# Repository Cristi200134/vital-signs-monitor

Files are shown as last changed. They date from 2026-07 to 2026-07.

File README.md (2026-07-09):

# VitalMonitor

Portable four-parameter vital-signs monitor (ECG, SpO2, temperature, respiration), built from scratch on an ESP32 for a biomedical engineering bachelor's at UMFST "G.E. Palade" Targu Mures. It reproduces the core functions of a clinical patient monitor using accessible parts. Working proof of concept, not a certified medical device.







## Highlights

- Four vital signs on one platform: heart rate from the ECG, SpO2, temperature, and respiration derived from the pulse signal.
- QRS detection validated on the MIT-BIH Arrhythmia Database (ANSI/AAMI EC57): F1 98.9%.
- Full engineering pack: schematic, costed bill of materials, 3D-printed enclosure, thesis.
- 3rd place at the Marisiensis International Medical Congress (UMFST, 2026).

## What it does

- ECG with heartbeat detection, SpO2 and temperature, plus a respiratory rate derived from the optical pulse signal.
- Local OLED display and a real-time web interface over the device's own WiFi access point.
- Three-level alarms with LED and buzzer, plus session logging to a microSD card with a real-time clock.

## Hardware

- ESP32 (dual core, FreeRTOS).
- ECG: AD8232 instrumentation amplifier and an external 16-bit ADC (ADS1115, 250 SPS), with a Butterworth filter cascade (high-pass 0.5 Hz, low-pass 40 Hz, notch 50 Hz, about 66 dB rejection at 50 Hz).
- SpO2 and respiration: MAX30102 optical sensor (ratio-of-ratios; respiration from the infrared DC modulation).
- Temperature: DS18B20. Clock: DS3231. Display: 128x64 OLED. Storage: microSD.
- Power: 1800 mAh LiPo, boost to 5 V, separate AMS1117 3.3 V rail for the analog section.
- Enclosure: plywood body with 3D-printed PLA panels (drawings in `hardware/`).

## Firmware

- C++/Arduino on FreeRTOS, eight tasks pinned across both cores by clinical priority, two mutexes (data and I2C), I2C at 400 kHz.
- ADS1115 runs in continuous mode so a 250 SPS ECG stream does not block the shared I2C bus.
- QRS detection: a simplified Pan-Tompkins (5-point derivative, squaring, 148 ms moving-window integration, adaptive SPKI/NPKI threshold, 200 ms refractory, averaging over 16 RR intervals).

## Validation

Heartbeat detection (simplified Pan-Tompkins) was tested on the MIT-BIH database, about 70,000 annotated beats over 30 records, with a 150 ms matching tolerance, following ANSI/AAMI EC57.

| Metric | Value | Method |
|---|---|---|
| Sensitivity (Se) | 98.66% | MIT-BIH, 30 records, ~70,000 beats |
| Positive predictivity (+P) | 99.11% | same |
| F1 score | 98.9% | same |
| ECG filter | SNR > 60 dB, stable (poles inside the unit circle) | simulation |

## Known limitations 

- The false-alarm rate is above the target I set for it.
- Latency, CPU load and battery life are budget estimates, not bench measurements.
- It is a research prototype, not a certified medical device.

## Repository structure

- `firmware/` ESP32 source (config, sensors, FreeRTOS tasks, web server).
- `hardware/` schematic (PDF), bill of materials, enclosure files (STL).
- `validation/` MATLAB scripts and the MIT-BIH validation.
- `docs/` thesis extract, device photos, validation captures.

## Tech

ESP32, FreeRTOS, C++, AD8232, ADS1115, MAX30102, DS18B20, MATLAB, PlatformIO.

## Author

Cristi Dica, biomedical engineer, Targu Mures. 

## License

MIT. See `LICENSE`.

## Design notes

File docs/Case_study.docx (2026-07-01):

Technical Case Study

VitalMonitor: a portable four-parameter vital signs monitor on the ESP32 platform

Dimension | Detail
Domain | biomedical engineering, embedded systems, biomedical signal processing
Platform | ESP32-WROOM-32 (dual core), C++/Arduino, FreeRTOS, PlatformIO
Parameters | ECG with heart rate, SpO2, temperature (measured directly); respiration (derived from the PPG signal)
Scope covered | hardware architecture, firmware, web application, CAD enclosure, numerical validation
Headline result | QRS detection on MIT-BIH: Se 98.67% / +P 99.11% / F1 98.89%
Cost | under 607 RON in components, below one tenth of a commercial multiparameter monitor
Battery life | about 7.6 h in active mode (1800 mAh LiPo, roughly 236 mA draw)

# 1. Context and problem

Patient deterioration is almost always preceded by changes in vital signs, which is why continuous monitoring is part of clinical practice and of standardized scores such as NEWS2. The barrier is not what we measure but access: classic multiparameter monitoring relies on expensive, bulky equipment tied to the ward. Outside the hospital, in home care or in resource-limited settings, it is missing.

The design question was whether the four common vital signs can be integrated on a single portable platform, an order of magnitude cheaper than a commercial monitor, without sacrificing the reliability of the part that matters most clinically, the correct detection of heartbeats.

# 2. Objectives and requirements

Functional requirements were fixed before implementation, each with a measurable criterion. The table summarizes the final state against the objectives.

Code | Requirement | Criterion | Status
F1 | ECG acquisition and analysis | QRS detection validated on clinical data | met (MIT-BIH)
F2 | SpO2 estimation | formula vs reference, Bland-Altman analysis | partial (subject validation pending)
F3 | heart rate | derived from ECG, averaged over 16 RR intervals | met
F4 | temperature | dedicated digital sensor | met
F5 | respiration | derived from signal, no extra sensor | met (on test signal)
F6 | real-time display | latency under 500 ms | met (estimated budget)
N1 | low cost | fraction of a commercial monitor | met (under 607 RON)

# 3. System architecture

The system is organized into six functional zones: analog acquisition, digital sensors, processing, power, display and communication. Coordination is handled by a dual-core ESP32, chosen over an Arduino Uno board for its compute headroom, built-in WiFi, and the ability to separate real-time acquisition from display and communication.

Three sensor chains produce four vital values. The ECG chain yields heart rate through QRS detection. The optical sensor yields oxygen saturation and, from the same signal, respiratory rate. The digital sensor yields temperature. Heart rate is therefore derived from the ECG, not from the optical sensor, and respiration is derived from the modulation of the pulse signal.

# 4. Engineering decisions and trade-offs

## 4.1. ECG chain and 16-bit conversion

The ECG signal is on the order of millivolts and easily corrupted, so it is captured by the AD8232 instrumentation amplifier (fixed gain of 100 V/V, common-mode rejection typically 86 dB up to 60 Hz, Driven Right Leg loop). Conversion does not use the ESP32 internal converter, which is too noisy and only 12-bit, but an external 16-bit ADS1115 on the ±6.144 V range. One quantization step is LSB = 6.144 / 32768 = 187.5 µV, that is about 1.875 µV referred to the electrodes after the gain of 100, fine enough for the QRS complex. The sampling rate is 250 SPS, above twice the 40 Hz useful band, the choice being driven by the accuracy of locating the R peak.

## 4.2. Continuous mode on the ADS1115

A subtle but important decision was running the converter in continuous mode rather than one-shot. In one-shot, each conversion at 250 SPS blocked the I2C bus for about 4 ms, starving the optical sensor, the clock and the display, which share that bus. In continuous mode the firmware reads the result register in about 0.5 ms, leaving the bus free for the rest of the interval. This was a system integration problem, not an algorithmic one, and it shows how much access scheduling on a shared resource matters.

## 4.3. QRS detection, a simplified Pan-Tompkins

Beat detection reproduces the core of the Pan-Tompkins algorithm: a five-point derivative, squaring, integration over a 37-sample moving window (148 ms at 250 SPS), and an adaptive threshold with two exponential estimates, one for the signal (SPKI) and one for noise (NPKI), with T = NPKI + 0.25 · (SPKI - NPKI). A 200 ms refractory period and averaging over 16 RR intervals stabilize the rate. It is a simplified variant, without searchback and without dual thresholds, a trade-off justified by real-time execution on a microcontroller.

## 4.4. SpO2 and respiration from the same optical signal

Saturation uses the ratio-of-ratios method, R = (AC_red/DC_red) / (AC_infrared/DC_infrared), mapped through the empirical curve SpO2 = -45.06·R^2 + 30.35·R + 94.85 from the sensor application note. From the DC component of the infrared signal, modulated by breathing through cardio-respiratory coupling, the firmware extracts respiratory rate with a band-pass filter formed from the difference of two exponential moving averages (band roughly 0.016 to 0.8 Hz) and zero-crossing detection. A single optical sensor thus covers two parameters, with no extra hardware.

## 4.5. Concurrency across two cores

The firmware runs on FreeRTOS with eight tasks explicitly pinned across the two cores. On the acquisition core, ECG has the highest priority, followed by the optical sensor, alarms, temperature, display and buttons; the other core runs the WebSocket server and SD logging. Two mutexes, one on the shared data structure and one on the I2C bus, prevent collisions. The separation guarantees that the deterministic 4 ms acquisition is never delayed by display or communication.

## 4.6. Power with dual regulation

Power starts from an 1800 mAh LiPo battery, with dedicated charging and a master switch. A boost converter produces a 5 V rail, from which an AMS1117 linear regulator derives a 3.3 V supply used only by the analog section, separate from the digital supply of the ESP32. The dual regulation keeps noisy consumers away from the sensitive measurement chain. Battery voltage is tracked through a resistive divider on the converter second channel.

# 5. Technical challenges solved

### The offset transient that dropped sensitivity to 49%

On the first run of detection on MIT-BIH, sensitivity was only 49%. The cause was not the algorithm but the data: the raw signal has a large DC component which, passed through the high-pass filter, produced a large startup transient. The adaptive threshold, computed exactly on that beginning, was inflated and missed most beats. The fix was to remove the signal mean and to skip the first second when initializing the threshold. Sensitivity rose to 98.67%. The lesson, statable directly to the committee: a correct algorithm can appear to fail because of a data preparation issue.

### Filter chain stability

The filter cascade was confirmed stable by the pole positions of each biquad section, all inside the unit circle. The frequency response shows 3 dB attenuation at the 0.5 and 40 Hz cutoffs and about 66 dB at 50 Hz, enough to suppress mains interference. After filtering, the signal-to-noise ratio exceeds the 60 dB threshold considered necessary for a reliable clinical reading.

# 6. Validation and results

Validation was designed component by component, with the established metric for each. The important distinction, which a committee values, is between what was validated on real clinical data and what was estimated or simulated.

Component | Method and result | Type
QRS detection | MIT-BIH, 30 records, about 70,000 beats, 150 ms tolerance, AAMI EC57 protocol: Se 98.67%, +P 99.11%, F1 98.89% | real clinical data
ECG filter | poles inside the unit circle (stable), 3 dB at 0.5 and 40 Hz, about 66 dB at 50 Hz, SNR above 60 dB | simulation
SpO2 | error under 2% vs the reference table for R below 0.70; Bland-Altman analysis | deterministic + simulated
Display latency | budget under 500 ms (IEC 60601-2-27 reference) | estimate
CPU load | under 80% per core | estimate
Battery life | about 7.6 h in active mode | calculation from currents

Validation honesty: the Bland-Altman analysis for SpO2 used simulated pairs, not measurements on subjects with a reference co-oximeter. The principle is correct, but clinical validation of saturation remains future work. QRS detection, by contrast, was validated on real clinical data, which makes it the strongest part of the project.

# 7. Acknowledged limitations

- blood pressure is not measured; the system covers four of the five common parameters.
- SpO2 validation is on simulated pairs, not on subjects; empirical calibration of the R curve requires controlled desaturation studies.
- latency, CPU load, battery life and SNR are budgets and simulations from specifications, not bench measurements.
- QRS detection was validated as a MATLAB reimplementation with the same coefficients and thresholds as the firmware, not as the compiled binary running on the chip.
- there is no full-system functional validation on a human subject over time yet.
- it is a research prototype, not a certified device.

# 8. Standards considered

The design respected the spirit of the relevant standards framework, as an exercise in rigor: IEC 60601-1 and 60601-1-8 for safety and alarms, IEC 62304 for the software life cycle, ISO 14971 for risk management and ISO 80601-2-61 for pulse oximetry, in the context of the European Medical Device Regulation. The system was not submitted for certification, and this is stated explicitly.

# 9. Impact and what the project demonstrates

The project demonstrates the vertical integration of a complete medical device by a single person: from the sensitive analog chain and the real-time firmware, through the validated processing algorithms, to the web application, the CAD enclosure and the validation protocol. The value lies not in a new algorithm but in coherently bringing the four parameters together on a low-cost platform and validating the critical part on real clinical data, at a cost an order of magnitude below a commercial monitor.

# 10. Lessons and next steps

- integrating a shared resource (the I2C bus) can be more limiting than the algorithm itself; access scheduling matters.
- data preparation (offset, transients) can mask a correct algorithm; diagnosis separates the two.
- validation honesty, a clear separation between real data and estimates, is worth more than a polished number.
- next steps: validate SpO2 on subjects against a reference, bench-measure latency and battery life, run the detector on the actual binary, and a full integrated functional pilot.

# 11. Technology stack

Layer | Components
Hardware | ESP32-WROOM-32, AD8232, ADS1115 (16-bit), MAX30102, DS18B20, DS3231, 128x64 OLED, SD card, TP4056, MT3608, AMS1117, 1800 mAh LiPo
Firmware | C++/Arduino, FreeRTOS (8 tasks, 2 cores), PlatformIO, two mutexes, I2C at 400 kHz
Algorithms | simplified Pan-Tompkins, ratio-of-ratios, RIIV respiration, Butterworth biquad filters (HP/LP/notch)
Web | SoftAP, ESPAsyncWebServer, WebSocket, LittleFS, HTML/JS monitoring and history pages
Validation | MATLAB (14 scripts), MIT-BIH database via PhysioNet, numerical checks
Mechanics | CAD in Fusion 360, plywood body, 3D-printed PLA panels, aluminum profiles

# Selected references

[1] Pan J, Tompkins WJ. A real-time QRS detection algorithm. IEEE Trans Biomed Eng. 1985.

[2] Moody GB, Mark RG. The impact of the MIT-BIH Arrhythmia Database. IEEE EMB. 2001.

[3] Goldberger AL, et al. PhysioBank, PhysioToolkit, and PhysioNet. Circulation. 2000.

[4] AAMI. Testing and reporting performance of cardiac rhythm algorithms (EC57).

[5] Giavarina D. Understanding Bland-Altman analysis. Biochem Med. 2015.

[6] Charlton PH, et al. Breathing rate estimation from the ECG and PPG: a review. IEEE Rev Biomed Eng. 2018.

[7] Nitzan M, Romem A, Koppel R. Pulse oximetry: fundamentals and technology update. 2014.

[8] Analog Devices, AD8232 datasheet; Maxim, MAX30102 / AN6409; Espressif, ESP32-WROOM-32 datasheet.

Indicative case study, compiled from the code and data of the VitalMonitor project.

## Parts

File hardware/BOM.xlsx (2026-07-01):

VitalMonitor — Listă de materiale (BOM)
Prețuri în RON. Electronica: prețuri din lucrare (Anexa B). Carcasă: estimativ, de verificat.
Nr. | Categorie | Componentă | Cant. | Preț (RON)
1 | Electronică | Placă de dezvoltare ESP32-WROOM-32 (DevKit1) | 1 | 42.00
2 | Electronică | Modul senzor ECG AD8232 (kit cu electrozi și cabluri) | 1 | 39.25
3 | Electronică | Senzor pulsoximetru MAX30102 (puls și SpO2) | 1 | 26.99
4 | Electronică | Senzor de temperatură impermeabil DS18B20 (sondă) | 1 | 7.10
5 | Electronică | Modul ADC ADS1115 (16 biți, I2C) | 1 | 14.44
6 | Electronică | Modul RTC DS3231 cu baterie LIR2032 | 1 | 26.16
7 | Electronică | Afișaj OLED 0,96″ I2C, SSD1306, 128×64 px | 1 | 13.74
8 | Electronică | Acumulator LiPo 103450, 3,7 V, 1800 mAh | 1 | 83.99
9 | Electronică | Modul de încărcare TP4056 USB-C, cu protecție | 1 | 3.90
10 | Electronică | Modul de ridicare a tensiunii MT3608 (HW-626) | 1 | 6.66
11 | Electronică | Regulator de tensiune AMS1117, 3,3 V | 1 | 4.07
12 | Electronică | Modul cititor microSD (SPI) | 1 | 3.62
13 | Electronică | Card microSD 32 GB (din stoc propriu) | 1 | 0.00
14 | Electronică | Buton PBS-110 (start/stop monitorizare) | 1 | 1.26
15 | Electronică | Buton PBS-110 (mod overnight) | 1 | 2.06
16 | Electronică | Buton PBS-110 (marcare eveniment) | 1 | 2.06
17 | Electronică | Buton PBS-110 (silențiere alarmă) | 1 | 1.49
18 | Electronică | Buton capacitiv TTP223 (touch) | 2 | 5.00
19 | Electronică | Întrerupător On-Off (alimentare principală) | 1 | 4.11
20 | Electronică | LED RGB de 10 mm, catod comun | 3 | 5.52
21 | Electronică | Buzzer pasiv 5 V | 2 | 2.40
22 | Electronică | Modul buzzer activ (rezervă) | 1 | 3.00
23 | Electronică | Conector aviatic 3 pini ELS-CA3P (metalic) | 2 | 40.66
24 | Electronică | Conector aviatic 4 pini ELS-CA4P (metalic) | 1 | 25.41
25 | Electronică | Set cabluri 24 AWG, 15 cm, negru | 1 | 3.04
26 | Electronică | Set cabluri 24 AWG, 15 cm, roșu | 1 | 3.04
27 | Electronică | Rezistență 4,7 kΩ, film metalic (pull-up I2C / 1-Wire) | 4 | 16.72
28 | Electronică | Rezistență 100 kΩ, 1 W, film metalic (divizor baterie) | 3 | 24.42
29 | Electronică | Rezistență 100 kΩ, 0,25 W, carbon (filtru anti-aliasing) | 2 | 7.74
30 | Electronică | Rezistență 10 kΩ, 0,25 W, carbon | 10 | 39.20
31 | Electronică | Rezistență 1 kΩ, 0,25 W, carbon (limitare LED RGB) | 3 | 11.70
32 | Electronică | Rezistență 100 Ω, 0,5 W, carbon (limitare buzzer) | 2 | 8.96
33 | Electronică | Rezistență 68 Ω, 0,25 W, carbon | 2 | 7.60
34 | Electronică | Rezistență 4,7 Ω, 0,25 W, carbon | 3 | 11.58
35 | Electronică | Condensator ceramic 100 nF, 50 V (decuplare VCC) | 7 | 25.55
36 | Electronică | Condensator electrolitic 10 µF, 50 V (Nichicon) | 4 | 13.32
37 | Electronică | Condensator electrolitic 10 µF, 35 V (Samwha) | 1 | 4.26
38 | Electronică | Tranzistor NPN BC547 (TO-92, comandă buzzer) | 1 | 1.47
39 | Electronică | Placă PCB prototip, 100 × 150 mm | 2 | 19.36
40 | Electronică | Set distanțiere M3, 15 mm (alamă) | 1 | 7.26
41 | Electronică | Set piulițe M3, inox A2 | 1 | 8.01
42 | Electronică | Bandă de cupru adezivă, 20 mm (ecranare ECG / cușcă Faraday) | 1 | 29.05
43 | Carcasă | Placaj de mesteacăn (corp carcasă, tăiat laser) — aprox. | 1 | 25.00
44 | Carcasă | Filament PLA (~200 g, piese imprimate 3D) — aprox. | 1 | 20.00
45 | Carcasă | Profile / colțare de aluminiu (rigidizare) — aprox. | 1 | 30.00
46 | Carcasă | Șuruburi de lemn, adeziv și accesorii de montaj — aprox. | 1 | 20.00
47 | Carcasă | Tabletă (ecran principal, montată pe panou frontal) — de completat | 1 | 0.00
 |  | TOTAL (RON) |  | 702.17

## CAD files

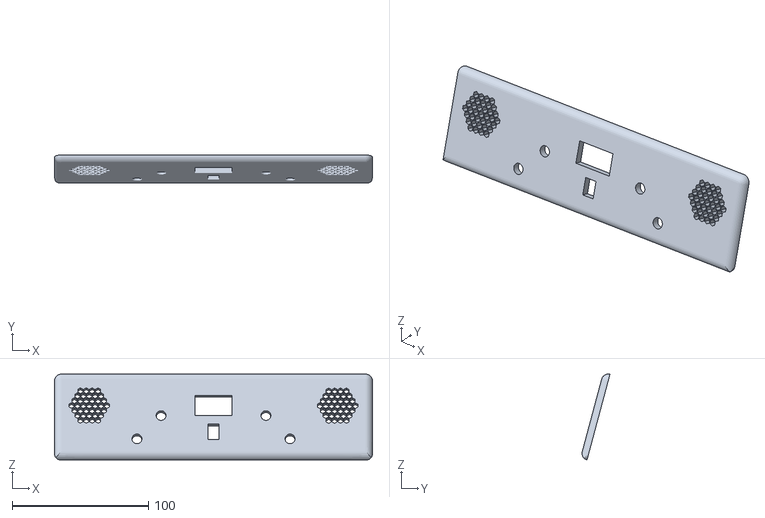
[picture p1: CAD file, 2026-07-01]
hardware/cad/zona oled+btn.stl
233.0 x 20.5 x 63.0

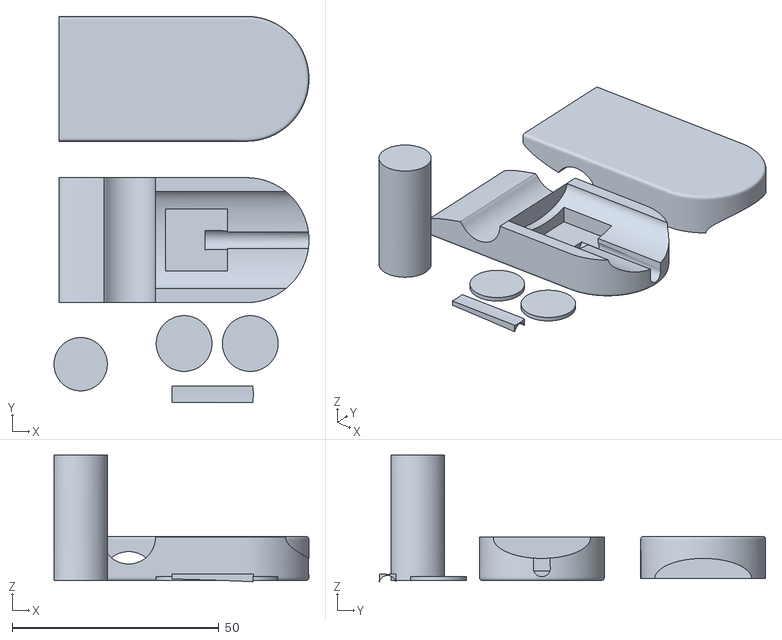
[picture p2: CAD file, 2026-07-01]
hardware/cad/pulsoximetru.stl
61.7 x 93.4 x 30.6

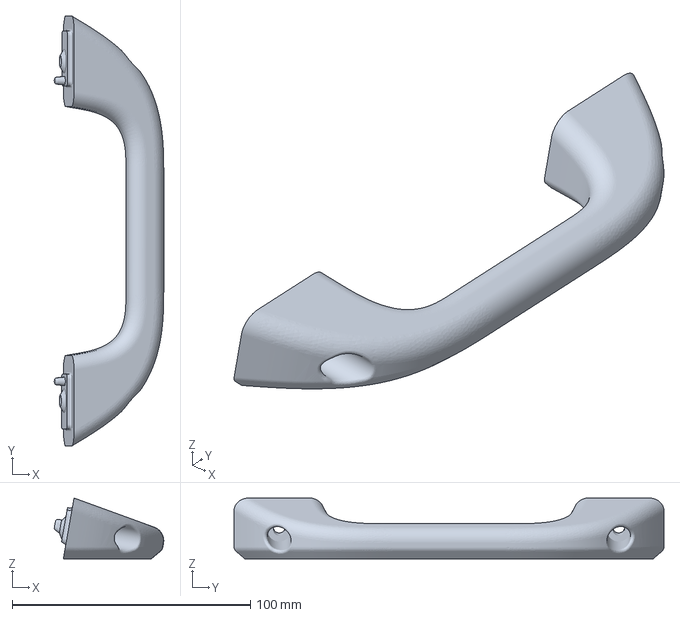
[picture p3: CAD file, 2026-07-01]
hardware/cad/maner.3mf
46.0 x 180.5 x 25.6 mm

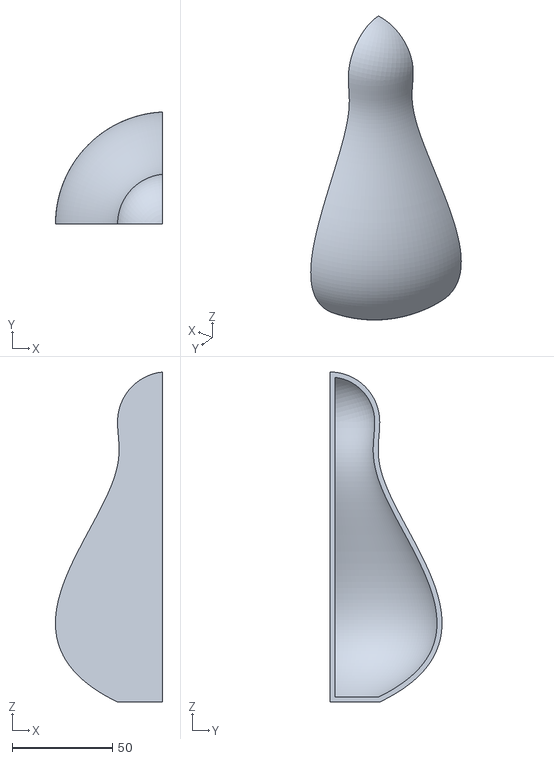
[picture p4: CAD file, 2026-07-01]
hardware/cad/zona led.stl
53.5 x 56.0 x 164.9

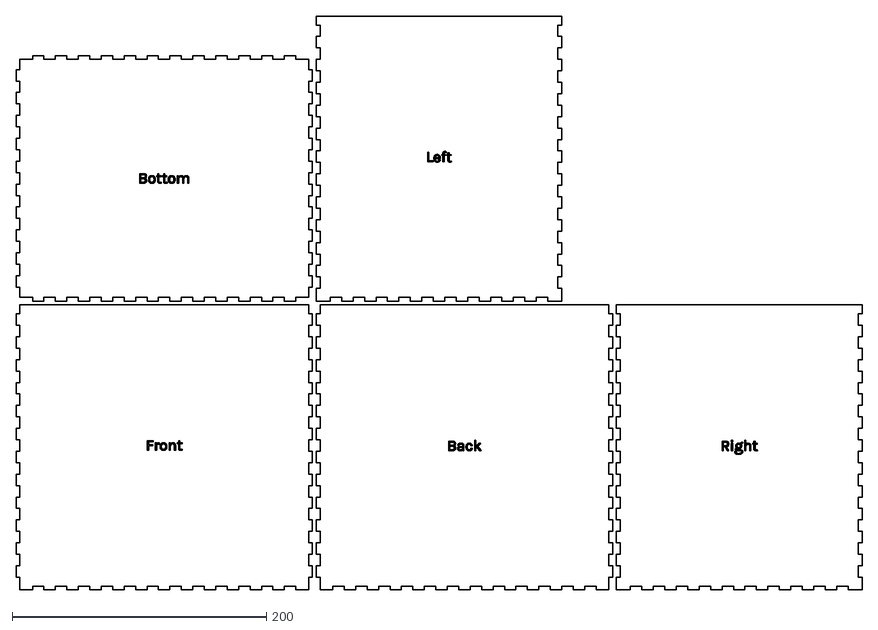
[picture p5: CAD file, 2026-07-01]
hardware/cad/box.dxf
665.0 x 451.0

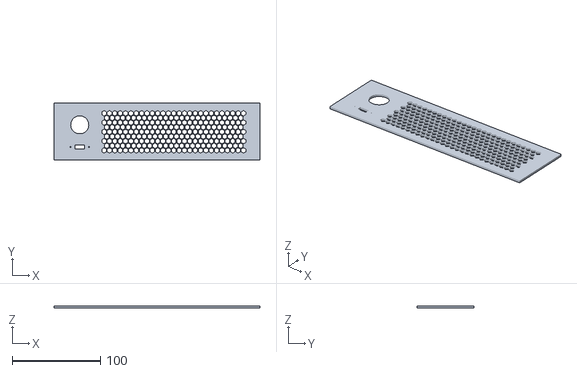
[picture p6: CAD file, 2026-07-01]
hardware/cad/panou spate.stl
233.0 x 65.0 x 2.50

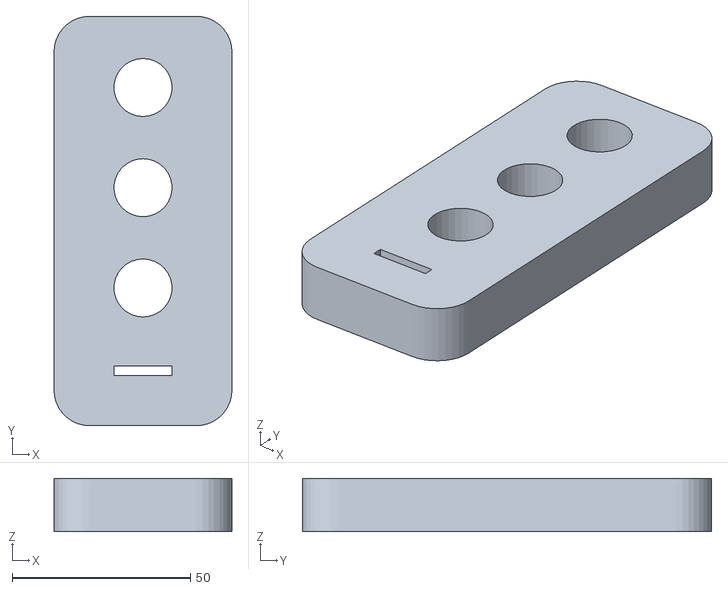
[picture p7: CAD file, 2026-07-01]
hardware/cad/zona conectori.stl
50.0 x 115.0 x 15.0

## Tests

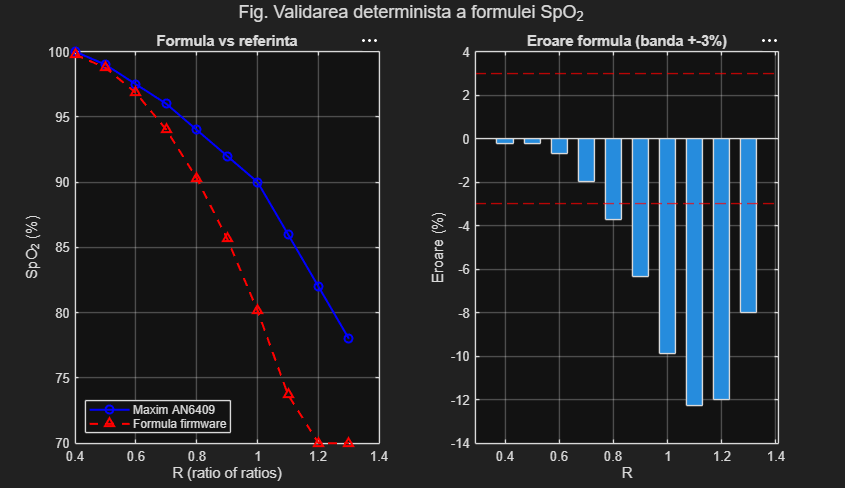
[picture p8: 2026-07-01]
docs/validation_photos/2spo2_bland1 (2).png

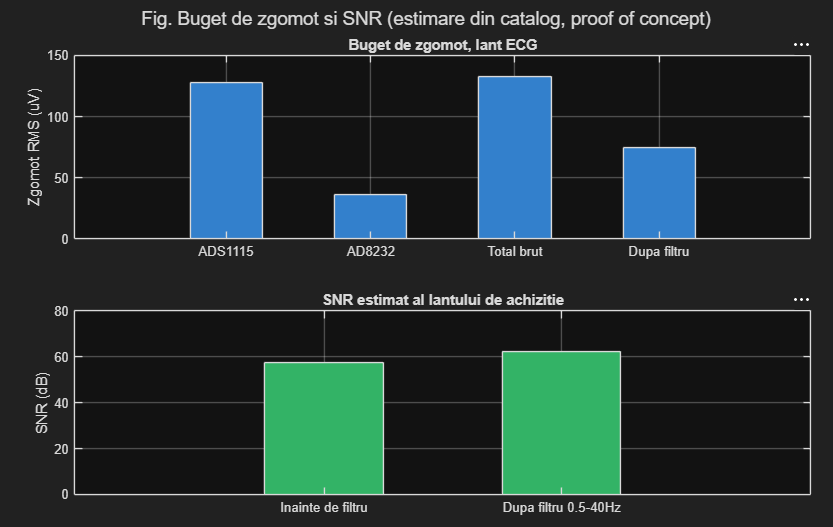
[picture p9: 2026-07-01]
docs/validation_photos/7zgomot_snr.png

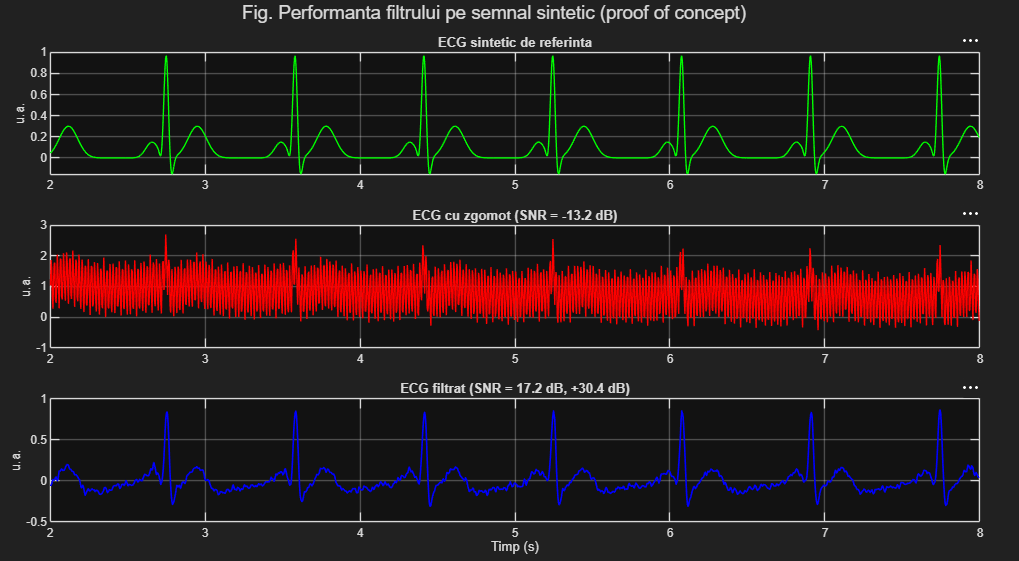
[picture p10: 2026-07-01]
docs/validation_photos/1filtru_ecg3 (2).png

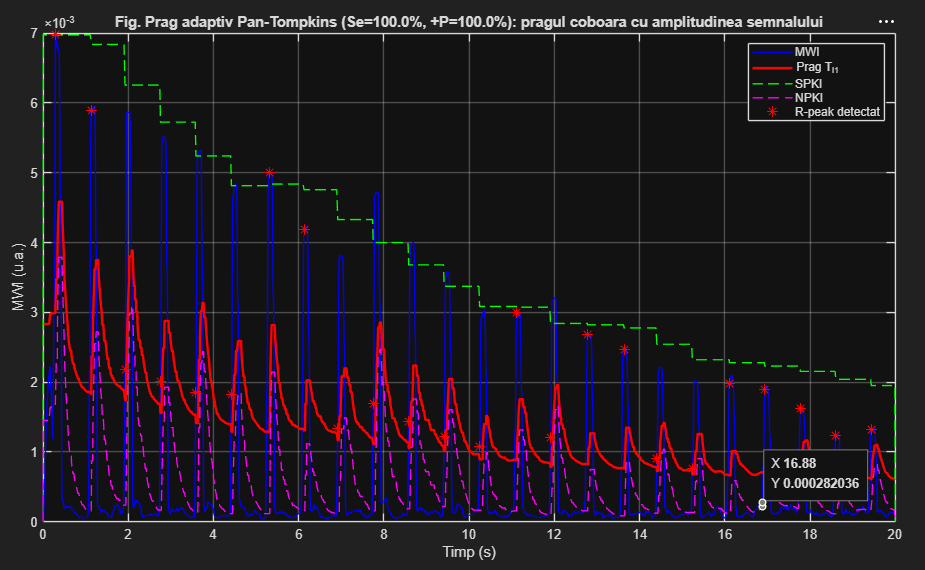
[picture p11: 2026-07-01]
docs/validation_photos/4prag_adaptiv.png

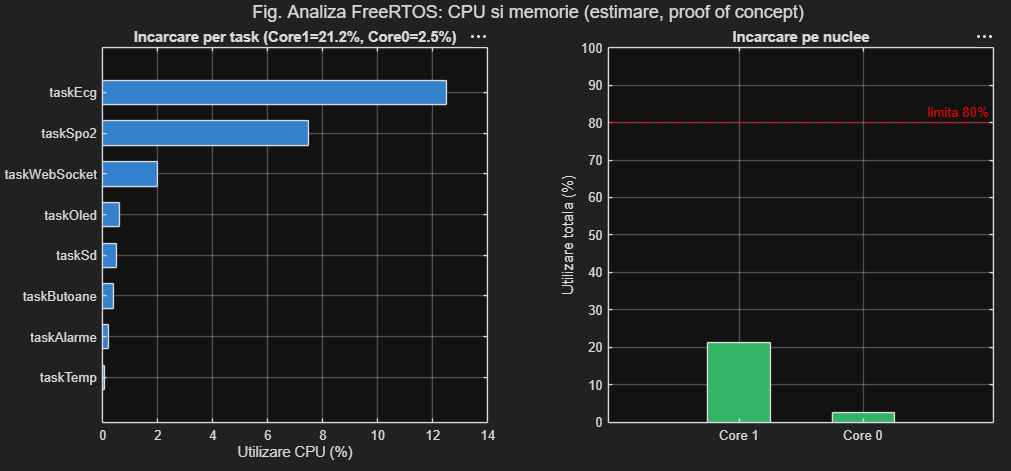
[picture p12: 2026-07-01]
docs/validation_photos/3cpu_freertos.png

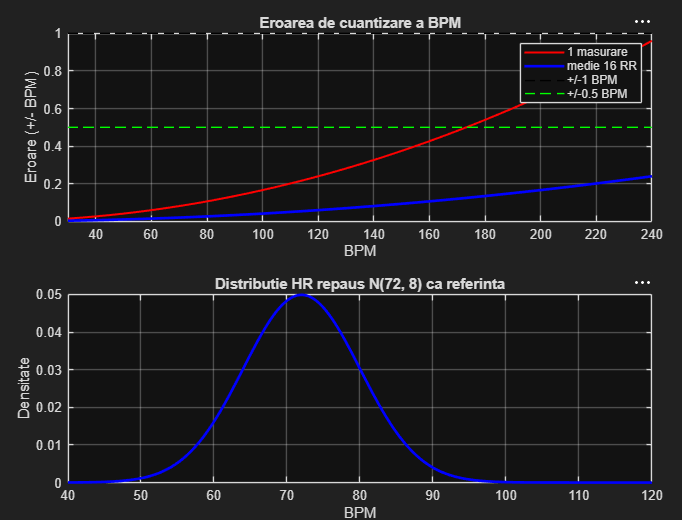
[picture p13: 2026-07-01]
docs/validation_photos/8precizie_bpm.png

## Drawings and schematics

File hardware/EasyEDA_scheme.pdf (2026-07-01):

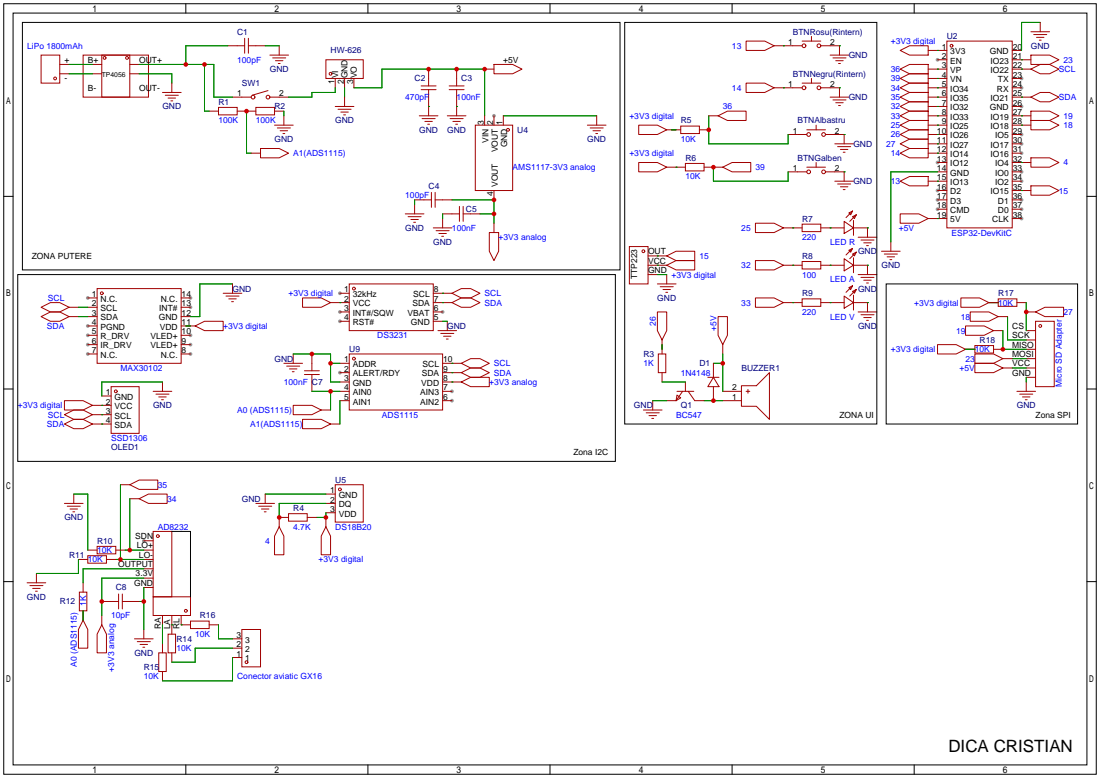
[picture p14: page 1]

HW-626 VI GND VO

VLED+ 10 VDD 11 GND 12 INT# 13 N.C. 14

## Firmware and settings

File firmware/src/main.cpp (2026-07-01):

//main.cpp — vitalmonitor (orchestrator freertos)
//workflow 
//  standby - [btn_rec sau "sesiune_noua" prin ws] - monitoring - [stop]
//arhitectura dual-core:
//  core 1: ecg(5) > spo2(4) > alarme(3) > temp(2) > oled(2) > btn(1)
//  core 0: websocket(3) > sd(2)
//mutex-uri:
//  g_mutex— acces campuri vitaldata (max 10ms wait)
//  g_i2c_mutex— serializeaza bus-ul i2c intre ads1115, max30102, rtc, oled

#define VITAL_DATA_IMPL
#include "vital_data.h"
#include "config.h"

#include <Arduino.h>
#include <Wire.h>
#include <WiFi.h>
#include <LittleFS.h>
#include <ESPAsyncWebServer.h>
#include <AsyncTCP.h>
#include <ArduinoJson.h>
#include <SD.h>
#include "esp_wifi.h"

#include "ecg_filter.h"
#include "ecg_sensor.h"
#include "spo2_sensor.h"
#include "temp_sensor.h"
#include "rtc_sensor.h"
#include "sd_logger.h"
#include "oled_display.h"
#include "ws_server.h"
#include "led_control.h"
#include "alarm_manager.h"

//obiecte globale
AsyncWebServer  g_server(WEB_PORT);
AsyncWebSocket  g_ws(WS_PATH);

EcgSensor    g_ecg;
Spo2Sensor   g_spo2;
TempSensor   g_temp;
RtcSensor    g_rtc;
SdLogger     g_sd;
OledDisplay  g_oled;
WsServer     g_wsrv;
LedControl   g_led;
AlarmManager g_alarm;

//task ecg — core 1, prioritate 5, 250 sps
//vtaskdelayuntil - 4ms intre esantioane
//i2c-ul protejat de g_i2c_mutex in ecgsensor::citestesi()
void taskEcg(void* pv) {
    g_ecg.init();
    TickType_t tWake = xTaskGetTickCount();

    while (true) {
        bool activ = false;
        if (LOCK_VITALS()) { activ = g_vitals.monitoring_active; UNLOCK_VITALS(); }
        g_ecg.citesteSi(&g_vitals, g_mutex, activ);
        vTaskDelayUntil(&tWake, pdMS_TO_TICKS(4));
    }
}

//task spo2 — core 1, prioritate 4, 50 sps
// g_i2c_mutex in spo2sensor::citestesi()
//cu mutex, spo2 asteapta pana ecg elibereaza bus-ul (4ms max)
void taskSpo2(void* pv) {
    g_spo2.init();
    TickType_t tWake = xTaskGetTickCount();

    while (true) {
        bool activ = false;
        if (LOCK_VITALS()) { activ = g_vitals.monitoring_active; UNLOCK_VITALS(); }
        if (activ) g_spo2.citesteSi(&g_vitals, g_mutex);
        vTaskDelayUntil(&tWake, pdMS_TO_TICKS(20));
    }
}

//task temperatura + rtc — core 1, prioritate 2, la 2s
//ds18b20 - onewire, fara i2c, fara mutex
//rtc - i2c, protejat in rtcsensor::actualizeazaora()
void taskTemp(void* pv) {
    g_temp.init();

    while (true) {
        //rtc-ul ruleaza mereu (avem nevoie pentru ceas si timestamp csv)
        g_rtc.actualizeazaOra(&g_vitals, g_mutex);

        bool activ = false;
        if (LOCK_VITALS()) { activ = g_vitals.monitoring_active; UNLOCK_VITALS(); }
        if (activ) g_temp.citesteSi(&g_vitals, g_mutex);

        vTaskDelay(pdMS_TO_TICKS(TEMP_INTERVAL_MS));
    }
}

//task oled — core 1, prioritate 2, refresh la 500ms
//disp.display() (i2c) e protejat in oleddisplay::afiseaza()
//in overnight: ecran afiseaza  "overnight" + ora curenta
void taskOled(void* pv) {
    g_oled.init();

    while (true) {
        VitalData snap = snapVitals();

        if (snap.overnight_active) g_oled.afiseazaOvernight(snap);
        else                       g_oled.afiseaza(snap);

        vTaskDelay(pdMS_TO_TICKS(500));
    }
}

//task websocket — core 0, prioritate 3
//"wave" la 100ms — batch ecg + spo2
//"num"  la 2s    — date numerice complete

void taskWebSocket(void* pv) {
    vTaskDelay(pdMS_TO_TICKS(2000));    //asteptam initializarea wifi

    TickType_t tWave    = xTaskGetTickCount();
    TickType_t tNumeric = xTaskGetTickCount();
    TickType_t tCleanup = xTaskGetTickCount();

    while (true) {
        TickType_t tNow = xTaskGetTickCount();

        if ((tNow - tWave) >= pdMS_TO_TICKS(WAVE_TX_MS)) {
            tWave = tNow;
            g_wsrv.trimiteBatch(&g_vitals, g_mutex, &g_ws);
        }

        if ((tNow - tNumeric) >= pdMS_TO_TICKS(NUMERIC_TX_MS)) {
            tNumeric = tNow;
            if (LOCK_VITALS()) {
                g_vitals.ws_clients = (uint8_t)g_ws.count();
                UNLOCK_VITALS();
            }
            g_wsrv.trimiteNumeric(&g_vitals, g_mutex, &g_ws);
        }

        //cleanup la 5s pe core 0 (acelasi cu ws-ul) — evita race condition
        if ((tNow - tCleanup) >= pdMS_TO_TICKS(5000)) {
            tCleanup = tNow;
            g_ws.cleanupClients();
        }

        vTaskDelay(pdMS_TO_TICKS(10));
    }
}

//task sd logger — core 0, prioritate 2, la 1s
//tranzitie monitoring false->true: deschide fisier nou
//tranzitie monitoring true->false: inchide fisierul
//incrementeaza probe_count si uptime_s la fiecare rand scris
void taskSd(void* pv) {
    bool sdOk = g_sd.init();
    if (LOCK_VITALS()) {
        g_vitals.sd_ok      = sdOk;
        g_vitals.sd_free_gb = sdOk ? g_sd.spatioLiber() : 0.0f;
        UNLOCK_VITALS();
    }

    bool wasActiv = false;

    while (true) {
        VitalData snap = snapVitals();
        bool activ = snap.monitoring_active;

        if (activ && !wasActiv)   g_sd.deschideSesiune(snap);
        else if (!activ && wasActiv) g_sd.inchide();

        if (activ) {
            g_sd.scrieRand(snap);
            if (LOCK_VITALS()) {
                g_vitals.probe_count++;
                g_vitals.uptime_s++;
                g_vitals.sd_free_gb    = g_sd.spatioLiber();
                g_vitals.sd_almost_full = g_sd.aproapePlin();
                UNLOCK_VITALS();
            }
        }

        wasActiv = activ;
        vTaskDelay(pdMS_TO_TICKS(SD_LOG_INTERVAL_MS));
    }
}

//task alarme + led + buzzer — core 1, prioritate 3, la 500ms
//in standby: led albastru clipeste lent, buzzer-ul oprit
//in monitoring: led-ul si buzzer-ul urmaresc nivelul de alarma
void taskAlarme(void* pv) {
    g_alarm.init();
    g_led.init();

    while (true) {
        VitalData snap = snapVitals();

        if (snap.monitoring_active) {
            AlarmResult res = g_alarm.evalueaza(snap);

            //auto-exit din overnight, doar pentru alarmele physio (nu lead-off/baterie)
            if (snap.overnight_active && res.isPhysio && res.level >= 2) {
                if (LOCK_VITALS()) { g_vitals.overnight_active = false; UNLOCK_VITALS(); }
                snap.overnight_active = false;
                Serial.printf("[overnight] auto-exit: %s (nivel %d)\n", res.msg, res.level);
            }

            //auto-mark csv: pe tranzitia la nivel 3 (critic), marcheaza evenimentul
            //asa coloana "ev" din csv arata "DA" la momentul aparitiei alarmei critice
            static uint8_t prevAlarmLevel = 0;
            if (res.level >= 3 && prevAlarmLevel < 3) {
                g_sd.marcheazaEveniment();
                Serial.printf("[alarm-ev] critic auto-marcat in csv: %s\n", res.msg);
            }
            prevAlarmLevel = res.level;

            if (LOCK_VITALS()) {
                g_vitals.alarm_level = res.level;
                strncpy(g_vitals.alarm_msg, res.msg, sizeof(g_vitals.alarm_msg) - 1);
                UNLOCK_VITALS();
            }

            if (snap.overnight_active) {
                //in overnight: led galben fulger scurt la 10s, buzzer mut
                bool on = (millis() % 10000) < 200;
                digitalWrite(PIN_LED_R, on ? HIGH : LOW);
                digitalWrite(PIN_LED_G, on ? HIGH : LOW);
                digitalWrite(PIN_LED_B, LOW);
                noTone(PIN_BUZZER);
            } else {
                g_led.aplicaAlarma(res.level, snap.bat_pct);
                g_alarm.sunaBuzzer(res.level);
            }
        } else {
            //standby (eventual + overnight): albastru clipeste / overnight = stins
            if (snap.overnight_active) {
                digitalWrite(PIN_LED_R, LOW);
                digitalWrite(PIN_LED_G, LOW);
                digitalWrite(PIN_LED_B, LOW);
            } else {
                bool on = (millis() / 1000) % 2;
                digitalWrite(PIN_LED_R, LOW);
                digitalWrite(PIN_LED_G, LOW);
                digitalWrite(PIN_LED_B, on ? HIGH : LOW);
            }
            noTone(PIN_BUZZER);
        }

        vTaskDelay(pdMS_TO_TICKS(500));
    }
}

//task butoane — core 1, prioritate 1, polling la 50ms
//btn_men (gpio36 albastru — paginile oled
//btn_sil (gpio39 galben)  — silentiere buzzer 1 minut
//btn_sel (gpio14 negru)   — toggle overnight (single press)
//btn_rec (gpio13 rosu)   — start / stop monitorizare
//btn_ev  (gpio15 ttp223)  — marcheaza eveniment in csv
void taskButoane(void* pv) {
    bool prevMen = HIGH, prevSil = HIGH, prevSel = HIGH, prevRec = HIGH, prevEv = LOW;

    while (true) {
        bool curMen = digitalRead(PIN_BTN_MEN);
        bool curSil = digitalRead(PIN_BTN_SIL);
        bool curSel = digitalRead(PIN_BTN_SEL);
        bool curRec = digitalRead(PIN_BTN_REC);
        bool curEv  = digitalRead(PIN_BTN_EV);

        //btn_men — pagina urmatoare oled
        if (prevMen == HIGH && curMen == LOW) {
            g_oled.nextPagina();
        }

        //btn_sil — silentiere buzzer 1 minut 
        if (prevSil == HIGH && curSil == LOW) {
            g_alarm.mutePentru(BTN_SIL_MS);
            g_wsrv.trimiteCmdButon(&g_ws, "btn_sil");
            Serial.println("[btn_sil] buzzer silentiat 1 minut");
        }

        //btn_sel — toggle overnight 
        if (prevSel == HIGH && curSel == LOW) {
            bool nou = false;
            if (LOCK_VITALS()) {
                g_vitals.overnight_active = !g_vitals.overnight_active;
                nou = g_vitals.overnight_active;
                UNLOCK_VITALS();
            }
            g_wsrv.trimiteCmdButon(&g_ws, nou ? "overnight_on" : "overnight_off");
            Serial.printf("[btn_sel] overnight %s\n", nou ? "pornit" : "oprit");
        }

        //btn_rec — start / stop
        if (prevRec == HIGH && curRec == LOW) {
            if (LOCK_VITALS()) {
                g_vitals.monitoring_active = !g_vitals.monitoring_active;
                bool active = g_vitals.monitoring_active;

                if (active) {
                    g_vitals.probe_count        = 0;
                    g_vitals.uptime_s           = 0;
                    g_vitals.alarm_level        = 0;
                    g_vitals.alarm_msg[0]       = '\0';
                    g_vitals.session_start_unix = g_rtc.unixTime();
                } else {
                    //reset valori la stop — interfata  "—"
                    g_vitals.bpm        = 0.0f; g_vitals.hr_valid   = false;
                    g_vitals.spo2       = 0.0f; g_vitals.spo2_valid = false;
                    g_vitals.temp_c     = 0.0f; g_vitals.temp_valid = false;
                    g_vitals.resp_rpm   = 0.0f; g_vitals.resp_valid = false;
                    g_vitals.alarm_level = 0;   g_vitals.alarm_msg[0] = '\0';
                }
                UNLOCK_VITALS();

                g_wsrv.trimiteCmdButon(&g_ws, active ? "btn_start" : "btn_stop");
                Serial.printf("[btn_rec] monitorizare %s\n", active ? "pornita" : "oprita");
            }
        }

        //btn_ev — eveniment pacient (panic button)
        if (prevEv == LOW && curEv == HIGH) {
            g_sd.marcheazaEveniment();
            g_wsrv.trimiteCmdButon(&g_ws, "btn_event");
            //3 bipuri scurte de confirmare
            for (int i = 0; i < 3; i++) {
                tone(PIN_BUZZER, 1200, 150);
                vTaskDelay(pdMS_TO_TICKS(220));
            }
            noTone(PIN_BUZZER);
            Serial.println("[btn_ev] eveniment marcat");
        }

        prevMen = curMen; prevSil = curSil; prevSel = curSel;
        prevRec = curRec; prevEv  = curEv;
        vTaskDelay(pdMS_TO_TICKS(BTN_DEBOUNCE_MS / 4));
    }
}

//callback websocket — primeste comenzi json de la interfata
void onWsEvent(AsyncWebSocket* server, AsyncWebSocketClient* client,
               AwsEventType type, void* arg, uint8_t* data, size_t len)
{
    if (type == WS_EVT_CONNECT) {
        Serial.printf("[ws] client #%u conectat (%s)\n",
                      client->id(), client->remoteIP().toString().c_str());
        if (LOCK_VITALS()) { g_vitals.ws_clients = (uint8_t)server->count(); UNLOCK_VITALS(); }
        g_wsrv.trimiteNumericLaClient(&g_vitals, g_mutex, client);
    }
    else if (type == WS_EVT_DISCONNECT) {
        Serial.printf("[ws] client #%u deconectat\n", client->id());
        if (LOCK_VITALS()) { g_vitals.ws_clients = (uint8_t)server->count(); UNLOCK_VITALS(); }
    }
    else if (type == WS_EVT_DATA) {
        AwsFrameInfo* info = (AwsFrameInfo*)arg;
        if (!info->final || info->index != 0 || info->len != len
            || info->opcode != WS_TEXT) return;

        JsonDocument doc;
        if (deserializeJson(doc, data, len)) return;
        const char* cmd = doc["cmd"] | "";

        //porneste monitorizarea cu date pacient
        if (strcmp(cmd, "sesiune_noua") == 0) {
            if (LOCK_VITALS()) {
                JsonObject pac = doc["pacient"];
                String numeFull = String(pac["prenume"] | "") + "_" +
                                  String(pac["nume"]    | "");
                strncpy(g_vitals.patient_name, numeFull.c_str(),
                        sizeof(g_vitals.patient_name) - 1);
                strncpy(g_vitals.patient_id,
                        pac["id"] | "", sizeof(g_vitals.patient_id) - 1);
                strncpy(g_vitals.patient_diag,
                        pac["diag"] | "", sizeof(g_vitals.patient_diag) - 1);

                g_vitals.monitoring_active  = true;
                g_vitals.probe_count        = 0;
                g_vitals.uptime_s           = 0;
                g_vitals.alarm_level        = 0;
                g_vitals.alarm_msg[0]       = '\0';
                g_vitals.session_start_unix = g_rtc.unixTime();
                UNLOCK_VITALS();
            }
            g_wsrv.trimiteCmdButon(&g_ws, "btn_start");
            Serial.println("[ws] sesiune noua pornita");
        }
        else if (strcmp(cmd, "stop") == 0) {
            if (LOCK_VITALS()) {
                g_vitals.monitoring_active = false;
                g_vitals.bpm = 0; g_vitals.hr_valid   = false;
                g_vitals.spo2 = 0; g_vitals.spo2_valid = false;
                g_vitals.temp_c = 0; g_vitals.temp_valid = false;
                UNLOCK_VITALS();
            }
            g_wsrv.trimiteCmdButon(&g_ws, "btn_stop");
        }
        else if (strcmp(cmd, "eveniment") == 0) {
            g_sd.marcheazaEveniment();
        }
        else if (strcmp(cmd, "silentiat") == 0) {
            bool val = doc["val"] | false;
            if (val) g_alarm.mutePentru(BTN_SIL_MS);
            else     g_alarm.dezMute();
        }
        else if (strcmp(cmd, "set_ora") == 0) {
            g_rtc.seteazaOra(
                doc["an"] | 2024, doc["luna"] | 1, doc["zi"] | 1,
                doc["h"]  | 0,    doc["min"]  | 0, doc["sec"]| 0);
        }
        else if (strcmp(cmd, "export") == 0) {
            String filename = g_sd.fisierCurent();
            JsonDocument resp;
            resp["tip"]      = "export_url";
            resp["url"]      = ("/download?file=" + filename).c_str();
            resp["filename"] = filename.c_str();
            char buf[256];
            size_t l = serializeJson(resp, buf, sizeof(buf));
            client->text(buf, l);
        }
    }
}

//initwifi, initlittlefs, initwebserver
static void initWiFi() {
    WiFi.mode(WIFI_AP);
    WiFi.softAP(WIFI_AP_SSID, WIFI_AP_PASS,
                WIFI_AP_CHANNEL, WIFI_AP_HIDDEN, WIFI_AP_MAX_CONN);
    IPAddress ip(192, 168, 4, 1);
    WiFi.softAPConfig(ip, ip, IPAddress(255, 255, 255, 0));
    Serial.printf("[wifi] ap: '%s'  ip: %s\n",
                  WIFI_AP_SSID, WiFi.softAPIP().toString().c_str());
}

static void initLittleFS() {
    if (!LittleFS.begin(true)) {
        Serial.println("[fs] littlefs eroare!"); return;
    }
    Serial.println("[fs] littlefs ok");
}

static void initWebServer() {
    g_ws.onEvent(onWsEvent);
    g_server.addHandler(&g_ws);

    g_server.on("/", HTTP_GET, [](AsyncWebServerRequest* r) {
        r->send(LittleFS, "/index.html", "text/html");
    });
    g_server.on("/history", HTTP_GET, [](AsyncWebServerRequest* r) {
        r->send(LittleFS, "/history.html", "text/html");
    });

    //lista fisierelor csv de pe sd
    g_server.on("/files", HTTP_GET, [](AsyncWebServerRequest* r) {
        String json = "[";
        if (g_sd.esteMontat()) {
            File dir = SD.open(SD_LOG_DIR);
            if (dir && dir.isDirectory()) {
                bool first = true;
                File f = dir.openNextFile();
                while (f) {
                    if (!f.isDirectory() && String(f.name()).endsWith(".csv")) {
                        if (!first) json += ",";
                        json += "\"" + String(f.name()) + "\"";
                        first = false;
                    }
                    f.close(); f = dir.openNextFile();
                }
                dir.close();
            }
        }
        json += "]";
        r->send(200, "application/json", json);
    });

    //download fisier csv
    g_server.on("/download", HTTP_GET, [](AsyncWebServerRequest* r) {
        if (!r->hasParam("file")) { r->send(400, "text/plain", "param lipsa"); return; }
        String fn = r->getParam("file")->value();
        if (fn.indexOf("..") >= 0 || !fn.endsWith(".csv"))
            { r->send(400, "text/plain", "invalid"); return; }
        String path = String(SD_LOG_DIR) + "/" + fn;
        if (!SD.exists(path.c_str())) { r->send(404, "text/plain", "negasit"); return; }
        r->send(SD, path.c_str(), "text/csv", true);
    });

    g_server.onNotFound([](AsyncWebServerRequest* r) {
        r->send(404, "text/plain", "404");
    });

    g_server.begin();
    Serial.printf("[http] server pe portul %d\n", WEB_PORT);
}

//setup
void setup() {
    Serial.begin(115200);
    delay(200);
    Serial.printf("\n[boot] %s v%s\n", DEVICE_NAME, FW_VERSION);

    //mutex-uri
    g_mutex     = xSemaphoreCreateMutex(); configASSERT(g_mutex);
    g_i2c_mutex = xSemaphoreCreateMutex(); configASSERT(g_i2c_mutex);

    //i2c + gpio
    Wire.begin(PIN_SDA, PIN_SCL);
    Wire.setClock(400000);

    pinMode(PIN_BTN_REC, INPUT_PULLUP);
    pinMode(PIN_BTN_SEL, INPUT_PULLUP);
    pinMode(PIN_BTN_SIL, INPUT);
    pinMode(PIN_BTN_MEN, INPUT);
    pinMode(PIN_BTN_EV,  INPUT);
    pinMode(PIN_LO_PLUS,  INPUT);
    pinMode(PIN_LO_MINUS, INPUT);

    pinMode(PIN_LED_R, OUTPUT); digitalWrite(PIN_LED_R, LOW);
    pinMode(PIN_LED_G, OUTPUT); digitalWrite(PIN_LED_G, LOW);
    pinMode(PIN_LED_B, OUTPUT); digitalWrite(PIN_LED_B, LOW);
    pinMode(PIN_BUZZER, OUTPUT); noTone(PIN_BUZZER);

    //led albastru = boot in curs
    digitalWrite(PIN_LED_B, HIGH);

    //rtc inainte de sd (timestamp-ul e necesar pentru csv)
    g_rtc.init();
    g_rtc.actualizeazaOra(&g_vitals, g_mutex);

    //wifi + http + littlefs
    initLittleFS();
    initWiFi();
    initWebServer();

    digitalWrite(PIN_LED_B, LOW);

    //self-test: led rgb + 2 bipuri
    //rosu -> verde -> albastru -> stins
    for (int pin : {PIN_LED_R, PIN_LED_G, PIN_LED_B}) {
        digitalWrite(pin, HIGH); delay(200); digitalWrite(pin, LOW);
    }
    tone(PIN_BUZZER, 1000, 80); delay(150);
    tone(PIN_BUZZER, 1400, 80); delay(150);
    noTone(PIN_BUZZER);

    //state initial: standby (led albastru clipeste — gestionat de taskalarme)
    Serial.println("[setup] stare: standby");
    Serial.printf("[setup] wifi: '%s'  →  http://192.168.4.1\n\n", WIFI_AP_SSID);

    //creare task-uri freertos
    xTaskCreatePinnedToCore(taskEcg,       "ECG",  STACK_ECG,       nullptr, 5, nullptr, 1);
    xTaskCreatePinnedToCore(taskSpo2,      "SPO2", STACK_SPO2,      nullptr, 4, nullptr, 1);
    xTaskCreatePinnedToCore(taskAlarme,    "ALM",  STACK_ALARMS,    nullptr, 3, nullptr, 1);
    xTaskCreatePinnedToCore(taskTemp,      "TEMP", STACK_TEMP,      nullptr, 2, nullptr, 1);
    xTaskCreatePinnedToCore(taskOled,      "OLED", STACK_OLED,      nullptr, 2, nullptr, 1);
    xTaskCreatePinnedToCore(taskButoane,   "BTN",  STACK_BUTTONS,   nullptr, 1, nullptr, 1);
    xTaskCreatePinnedToCore(taskWebSocket, "WS",   STACK_WEBSOCKET, nullptr, 3, nullptr, 0);
    xTaskCreatePinnedToCore(taskSd,        "SD",   STACK_SDLOG,     nullptr, 2, nullptr, 0);

    Serial.println("[setup] task-uri freertos pornite");
}

//loop — freertos preia controlul, loop() nu mai face nimic util
//cleanupclients() mutat in taskwebsocket (core 0) pentru a evita race condition
void loop() {
    vTaskDelay(portMAX_DELAY);
}

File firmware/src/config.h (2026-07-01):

#pragma once
//config centralizat —hardware (pini, constante, praguri) 
//versiune firmware
#define FW_VERSION   "1.0.0"
#define DEVICE_NAME  "VitalMonitor"

//pin map
//pinii speciali de pe esp32:
//gpio5  —strapping pin (boot: spi_clk_div), nu folosim ca sd_cs
//gpio12 —strapping pin (boot: flash voltage), nu poate fi input la boot
//gpio34,35,36,39 -input only, fara pull-up intern
//gpio2  —led intern pe devkit, ok dupa boot
//i2c (oled 0x3c, ads1115 0x48, ds3231 0x68, max30102 0x57)
#define PIN_SDA          21
#define PIN_SCL          22

//onewire pentru ds18b20
#define PIN_DS18B20       4

//ad8232 lead-off
#define PIN_LO_PLUS      34   //input only, fara pull-up intern
#define PIN_LO_MINUS     35   //input only, fara pull-up intern

//spi pentru cardul sd
//cs e pe gpio27 
//pull-up extern de 10k pe linia cs evita init fals la boot
#define PIN_SD_CS        27
#define PIN_SD_MOSI      23
#define PIN_SD_MISO      19
#define PIN_SD_SCK       18

//led rgb catod comun (high = aprins)
//verde-monitorizare activa, totul ok
//rosu-alarma critica (clipeste rapid)
//albastru-standby
#define PIN_LED_R        25
#define PIN_LED_G        33
#define PIN_LED_B        32

//buzzer pasiv
#define PIN_BUZZER       26


//btn_men (gpio36 albastru) —paginile oled (p1->p2->p3->p1)

//input only- pull-up extern 10k la 3.3v
//btn_sil (gpio39 galben) — silence buzzer 1 min
//  input only, pull-up extern 10k la 3.3v

//btn_sel (gpio14 negru) — overnight
// iese automat cand o val fiziologica iese din range
//pull-up intern
//btn_rec (gpio13 rosu) — start/stop sesiune
//btn_ev (gpio15 ttp223) — eveniment pacient (panic button)
//marcheaza ev in csv si notifica interfata

#define PIN_BTN_MEN      36   //albastru 
#define PIN_BTN_SIL      39   //galben  
#define PIN_BTN_SEL      14   //negru    
#define PIN_BTN_REC      13   //rosu    
#define PIN_BTN_EV       15   //ttp223  

//timpi butoane
#define BTN_DEBOUNCE_MS    200   //debounce general
#define BTN_SIL_MS       60000  //silence buzzer 1 minut

//debug toggles
#define BAT_DEBUG          1     //1 = log [bat] in serial la fiecare citire baterie

//wifi ap
#define WIFI_AP_SSID    "VitalMonitor"
#define WIFI_AP_PASS    "vital1234"
#define WIFI_AP_CHANNEL  1
#define WIFI_AP_HIDDEN   0    //0 = vizibil, 1 = ascuns
#define WIFI_AP_MAX_CONN 2    //maxim 2 clienti simultan

//webserver
#define WEB_PORT         80
#define WS_PATH          "/ws"

//frecvente esantionare
#define ECG_SPS          250  //hz, ads1115
#define SPO2_SPS          50  //hz, 
#define TEMP_INTERVAL_MS 2000 //ms, ds18b20 (conversie ~750ms)
#define SD_LOG_INTERVAL_MS 1000 //ms, o inregistrare pe secunda
#define NUMERIC_TX_MS    2000 //ms, cat de des trim numerele (bpm, temp, spo2, rr)
#define WAVE_TX_MS        100 //ms, cat de des trim batch-ul ecg/spo2

//ads1115
//canal 0 (a0): semnal ecg de la ad8232
//canal 1 (a1): tensiune baterie prin divizor 100k/100k
#define ADS_ECG_CHANNEL   0
#define ADS_BAT_CHANNEL   1
#define ADS_GAIN          GAIN_TWOTHIRDS  //+- 6.144v in ecg sensor
//conv tens baterie: vbat = raw * factor
//calibrarea de baza: 0.0001875 = 6.144 / 32768 (gain 2/3)
//calibrat experimental pe setup (cu multimetrul pe baterie):
//raw=20283 → vbat=3.80v → factor ≈ 0.0001875 (fara *2)
#define BAT_VOLT_FACTOR   0.0001875f
#define BAT_VOLT_FULL     4.20f   //v — baterie plina (lipo)
#define BAT_VOLT_EMPTY    3.00f   //v — baterie descarcata

//praguri alarme
//hr (bpm)
#define ALARM_HR_LOW_CRIT   45   //< 45 bpm = bradicardie critica
#define ALARM_HR_LOW_WARN   55   //< 55 bpm = atentionare
#define ALARM_HR_HIGH_WARN 110   //> 110 bpm = atentionare
#define ALARM_HR_HIGH_CRIT 130   //> 130 bpm = tahicardie critica

//spo2 (%)
#define ALARM_SPO2_CRIT     90   //< 90% = hipoxie critica
#define ALARM_SPO2_WARN     94   //< 94% = atentionare

//temperatura ('c)
#define ALARM_TEMP_LOW      35.0f  //< 35'c = hipotermie
#define ALARM_TEMP_HIGH     38.5f  //> 38.5'c = febra

//respiratie (rpm)
#define ALARM_RESP_LOW      10   //< 10 rpm = bradipnee
#define ALARM_RESP_HIGH     25   //> 25 rpm = tahipnee

//baterie (%)
#define ALARM_BAT_LOW       15   //< 15% = incarcare 
#define ALARM_BAT_CRIT       5   //< 5% = inchidere 

//coeficienti filtru ecg butterworth
//cascada 3 sectiuni biquad (IIR direct form II transpusa):
//  1. high-pass  butterworth ord.2  fc = 0.5 hz ; 250 sps
//  2. low-pass   butterworth ord.2  fc = 40  hz ; 250 sps
//  3. notch IIR  q=30               f0 = 50  hz ; 250 sps

//recalculati in matlab cu:
//butter(2, 0.5/125.0, 'high')
//butter(2, 40.0/125.0, 'low')
//iirnotch(50.0/125.0, 50.0/125.0/30)
//q=30 pentru notch → banda eliminata ~1.7 hz (49.15-50.85 hz)
//asa pastram semnalul util si scoatem precis 50 hz din retea

//sectiunea hp (0.5 hz ; 250 sps)
#define HP_B0   0.99115452f
#define HP_B1  (-1.98230904f)
#define HP_B2   0.99115452f
#define HP_A1  (-1.98223079f)
#define HP_A2   0.98238576f
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

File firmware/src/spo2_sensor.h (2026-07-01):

#pragma once
//spo2 din max30102 (i2c 0x57, 50 sps)
//pipeline per esantion (20ms):
//  1. lock_i2c -> sensor.check() -> getir/red -> unlock_i2c
//  2. verifica daca degetul e pe senzor (ir > 50000)
//  3. calcul spo2 din raportul r = (ac_red/dc_red) / (ac_ir/dc_ir)
//  4. acumulare waveform pentru websocket
//  5. detectie respiratie din modulatia dc a ir-ului

#include <Wire.h>
#include <MAX30105.h>
#include <heartRate.h>
#include "vital_data.h"
#include "config.h"

static const int  SPO2_WIN      = 100;     //fereastra calcul spo2
static const float IR_MIN_DEGET = 50000.0f; //sub pragul asta consideram ca nu e deget

class Spo2Sensor {
public:
    bool init() {
        if (!LOCK_I2C()) return false;
        bool ok = sensor.begin(Wire, I2C_SPEED_FAST);
        if (ok) {
            sensor.setup(60, 4, 2, 50, 411, 4096);
            sensor.setPulseAmplitudeRed(0x1F);
            sensor.setPulseAmplitudeIR(0x1F);
        }
        UNLOCK_I2C();

        if (!ok) {
            Serial.println("[spo2] max30102 negasit (i2c 0x57)!");
            return initOk = false;
        }
        initOk = true;
        Serial.println("[spo2] max30102 ok — 50 sps");
        return true;
    }

    //apelat din taskspo2 la fiecare 20ms
    void citesteSi(VitalData* v, SemaphoreHandle_t mtx) {
        if (!initOk) return;

        //citire i2c — serializata cu mutex (evita contention cu ecg)
        if (!LOCK_I2C()) return;
        sensor.check();
        bool avail  = sensor.available();
        uint32_t ir = 0, red = 0;
        if (avail) {
            ir  = sensor.getIR();
            red = sensor.getRed();
            sensor.nextSample();
        }
        UNLOCK_I2C();

        if (!avail) return;

        bool deget = (ir > (uint32_t)IR_MIN_DEGET);
        if (!deget) {
            irIdx = redIdx = 0;
            dcTracker = 0.0f; acPeak = 1.0f;
            //reset state-ul pentru respiratie ca la urmatoarea atingere sa porneasca curat
            respFast = 0.0f; respSlow = 0.0f; respPrev = 0.0f;
            respLastPeak = 0; respCount = 0; respIdx = 0;
            if (LOCK_VITALS()) {
                v->spo2 = 0; v->spo2_valid = false;
                v->pi   = 0; v->spo2_batch_idx = 0;
                v->resp_rpm = 0; v->resp_valid = false;
                UNLOCK_VITALS();
            }
            return;
        }

        //calcul respiratie din modulatia dc a ir-ului
        //dc-ul ir variaza aprox.0.5-2% cu respiratia (volumul sangvin in deget)
        //bandpass: respfast (lp 0.8 hz, scoate hr) minus respslow (lp 0.016 hz, scoate drift)
        //rezultat: 0.016-0.8 hz = 1-48 rpm
        if (respFast == 0.0f) {
            respFast = (float)ir;
            respSlow = (float)ir;
        } else {
            respFast = respFast * 0.9f   + (float)ir * 0.1f;
            respSlow = respSlow * 0.998f + respFast  * 0.002f;
        }
        float respSig = respFast - respSlow;

        //rising zero-crossing → eveniment respirator
        uint32_t tNow = millis();
        if (respSig > 0 && respPrev <= 0 && (tNow - respLastPeak) > 1500) {
            if (respLastPeak > 0) {
                uint32_t period = tNow - respLastPeak;
                if (period > 1500 && period < 10000) {  //6-40 rpm
                    respIntervals[respIdx] = (uint16_t)period;
                    respIdx = (respIdx + 1) % 5;
                    if (respCount < 5) respCount++;

                    if (respCount >= 3) {
                        uint32_t sum = 0;
                        for (uint8_t i = 0; i < respCount; i++) sum += respIntervals[i];
                        float rpm = 60000.0f / ((float)sum / respCount);
                        if (rpm >= 6.0f && rpm <= 40.0f) {
                            if (LOCK_VITALS()) {
                                v->resp_rpm   = rpm;
                                v->resp_valid = true;
                                UNLOCK_VITALS();
                            }
                        }
                    }
                }
            }
            respLastPeak = tNow;
        }
        respPrev = respSig;

        //timeout 30s fara respiratie -> invalid
        if (respLastPeak > 0 && (tNow - respLastPeak) > 30000 && respCount > 0) {
            if (LOCK_VITALS()) { v->resp_valid = false; v->resp_rpm = 0.0f; UNLOCK_VITALS(); }
            respCount = 0;
        }

        //acumulare in fereastra alunecatoare
        irBuf[irIdx   % SPO2_WIN] = ir;
        redBuf[redIdx % SPO2_WIN] = red;
        irIdx++; redIdx++;

        //calcul spo2 dupa ce s-a umplut fereastra
        if (irIdx >= SPO2_WIN) {
            float dcIR = 0, dcRed = 0;
            for (int i = 0; i < SPO2_WIN; i++) { dcIR += irBuf[i]; dcRed += redBuf[i]; }
            dcIR /= SPO2_WIN; dcRed /= SPO2_WIN;

            float acIR = 0, acRed = 0;
            for (int i = 0; i < SPO2_WIN; i++) {
                float dIR = irBuf[i] - dcIR, dRed = redBuf[i] - dcRed;
                acIR += dIR * dIR; acRed += dRed * dRed;
            }
            acIR  = sqrtf(acIR  / SPO2_WIN);
            acRed = sqrtf(acRed / SPO2_WIN);

            float R    = (acRed / dcRed) / (acIR / dcIR);
            float spo2 = constrain(-45.06f * R * R + 30.35f * R + 94.85f, 70.0f, 100.0f);
            float pi   = constrain(acIR / dcIR * 100.0f, 0.0f, 20.0f);

            if (LOCK_VITALS()) {
                v->spo2 = spo2; v->spo2_valid = true; v->pi = pi;
                UNLOCK_VITALS();
            }
        }

        //waveform pentru websocket — ac-coupled si auto-scaled
        //scoatem componenta dc -> ramane doar pulsul (ac)
        //auto-scalare la 25000 peak -> orice amplitudine arata bine in grafic
        dcTracker = dcTracker * 0.98f + (float)ir * 0.02f;
        float ac  = (float)ir - dcTracker;
        acPeak    = acPeak * 0.995f + fabsf(ac) * 0.005f;
        float scale = (acPeak > 100.0f) ? (25000.0f / acPeak) : 100.0f;
        uint16_t wv = (uint16_t)constrain(ac * scale + 32768.0f, 0.0f, 65535.0f);

        if (LOCK_VITALS()) {
            v->spo2_wave[v->spo2_batch_idx++] = wv;
            if (v->spo2_batch_idx >= VitalData::SPO2_BATCH) {
                v->spo2_batch_idx   = 0;
                v->spo2_batch_ready = true;
            }
            UNLOCK_VITALS();
        }
    }
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
